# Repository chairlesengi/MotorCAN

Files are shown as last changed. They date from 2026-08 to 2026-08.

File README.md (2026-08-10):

# MotorCAN
CANBus based FOC motor driver board designed for drone gimbal motors for node-based control, designed in KiCad.

Features:
  - STM32G431 processor core for SimpleFOC software and CAN communication
  - 3.3V CAN communication for easy logic level support
  - Runs on 20-26V DC
  - Integrated magnetic absolute encoder (MT6816CT)
  - Handles up to ~3A of motor current

This driver is designed to be a fully integrated solution that mounts to the back of a gimbal motor with a diametrically magnetized magnet. For that reason, it includes an absoulute magnetic encoder and leverages the current sensing capabilities of the DRV8316C driver to maintain a continous measurement of the position of the rotor of the motor and its magnetic field. Then, the STM32 running SimpleFOC calculates the exact currents on each phase needed to create a magnetic torque on the motor that is 90 degrees from the magnetic field and therefore gives the greatest overall control of the motor. This chip also has a 3.3V CAN chip so it can link up to a simple 4 wire network of muliple of these boards for applications like camera gimbals.

Credits:
SimpleFOC: https://github.com/simplefoc
KiCad: https://www.kicad.org

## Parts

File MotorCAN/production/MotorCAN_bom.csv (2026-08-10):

Designator | Footprint | Quantity | Value | LCSC Part #
C1, C2 | 0402 | 2 | 10pF
C10, C11, C12, C3, C4, C5, C6, C7, C8, C9 | 1206 | 10 | 10uF
C13, C16, C20, C21, C22, C23, C27, C28 | 0402 | 8 | 100nF
C14, C24, C25 | 0603 | 3 | 1uF
C15 | 0603 | 1 | 47nF
C17, C18, C19 | 0603 | 3 | 1nF
C26 | 1206 | 1 | 22uF
C29 | CP_Elec_6.3x7.7 | 1 | 100uF
CN1, CN4, CN5, CN6 | CONN-SMD_3P-P1.00_MEGASTAR_ZX-SH1.0-3PWT | 4 | ZX-SH1.0-3PWT | C7430445
CN2, CN3 | CONN-SMD_4P-P1.25_XUNPU_WAFER-GH1.25-4PWB | 2 | WAFER-GH1.25-4PWB | C3029379
D1 | D_SOD-123 | 1 | 4.7V Zener
D2 | SOT-23-3_L2.9-W1.3-P1.90-LS2.4-BR | 1 | PESD2CANFD24V-K | C5278878
D3 | D_SMB | 1 | 26V
FB1 | 0603 | 1 | 600@100MHz
J2 | AMASS_XT30PW-M_1x02_P2.50mm_Horizontal | 1 | PWR IN
J3 | AMASS_XT30PW-F_1x02_P2.50mm_Horizontal | 1 | PWR OUT
L1 | IND-SMD_L4.0-W4.0 | 1 | 47uH | C18222004
M1 | SolderWirePad_1x01_SMD_2x4mm | 1 | A
M2 | SolderWirePad_1x01_SMD_2x4mm | 1 | B
M3 | SolderWirePad_1x01_SMD_2x4mm | 1 | C
Q1 | SOT-23 | 1 | 2N7002
R1 | 0603 | 1 | 120
R10, R11, R13, R14, R9 | 0603 | 5 | 10k
R12, R2, R7 | 0603 | 3 | 100k
R3 | 0603 | 1 | 22k
R4, R5, R6, R8 | 0603 | 4 | 100
U1 | LQFP-48_L7.0-W7.0-P0.50-LS9.0-BL | 1 | STM32G431CBT6 | C529355
U2 | VQFN-40_L7.0-W5.0-P0.50-BL-EP5.7 | 1 | DRV8316CRRGFR | C5447274
U3 | SOIC-8_L4.9-W3.9-P1.27-LS6.0-BL | 1 | SN65HVD230DR | C12084
U4 | SOP-8_L4.9-W3.9-P1.27-LS6.0-BL-1 | 1 | MT6816CT-AKD-R | C2987620
X1 | CRYSTAL-SMD_4P-L2.0-W1.6-BL-A | 1 | XL7EL89CKI-111YLC-24M | C2965580

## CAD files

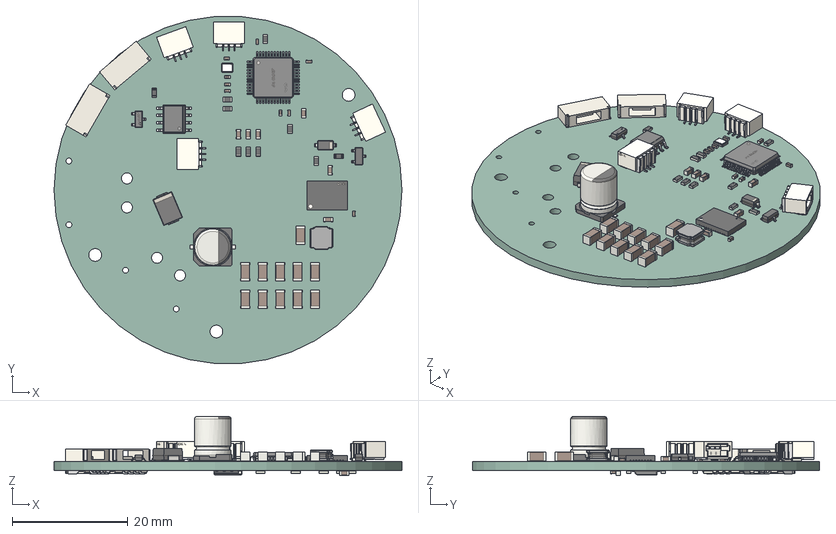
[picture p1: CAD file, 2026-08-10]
MotorCAN/.step
60.0 x 59.8 x 10.2 mm
C_0402_1005Metric x 10
SOT-23-3P_L2.9-W1.3-H1.0-LS2.4-P0.95
C_1206_3216Metric x 11
LQFP-48_L7.0-W7.0-H1.4-LS9.0-P0.50
CRYSTAL-SMD_4P-L2.0-W1.6-BL-A
C_0603_1608Metric x 7
R_0603_1608Metric x 15
CONN-SMD_3P-P1.00_MEGASTAR_ZX-SH1.0-3PWT x 4
SOIC-8_L4.9-W3.9-H1.7-LS6.0-P1.27
CP_Elec_6.3x7.7
IND-SMD_L4.0-W4.0-H1.9
VQFN-40_L7.0-W5.0-P0.50-BL-EP5.7
CONN-SMD_4P-P1.25_XUNPU_WAFER-GH1.25-4PWB x 2
D_SOD-123
SOT-23
D_SMB
SOP-8_L4.9-W3.9-P1.27-LS6.0-BL-1
MotorCAN_PCB

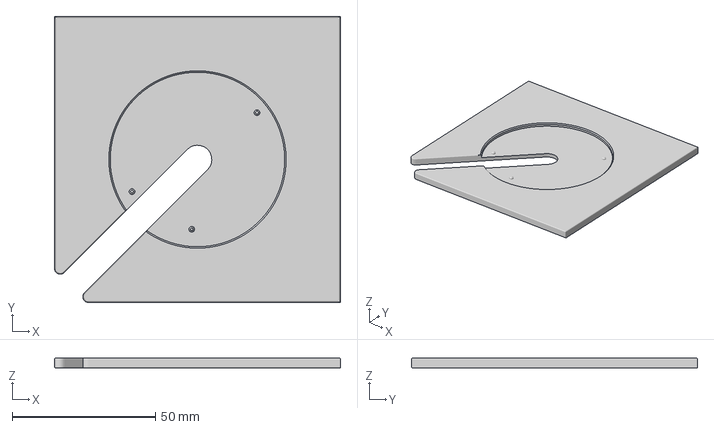
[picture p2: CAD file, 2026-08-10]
MotorCAN/HolderCAN.3mf
100.0 x 100.0 x 3.51 mm

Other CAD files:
MotorCAN/MotorCAN.step

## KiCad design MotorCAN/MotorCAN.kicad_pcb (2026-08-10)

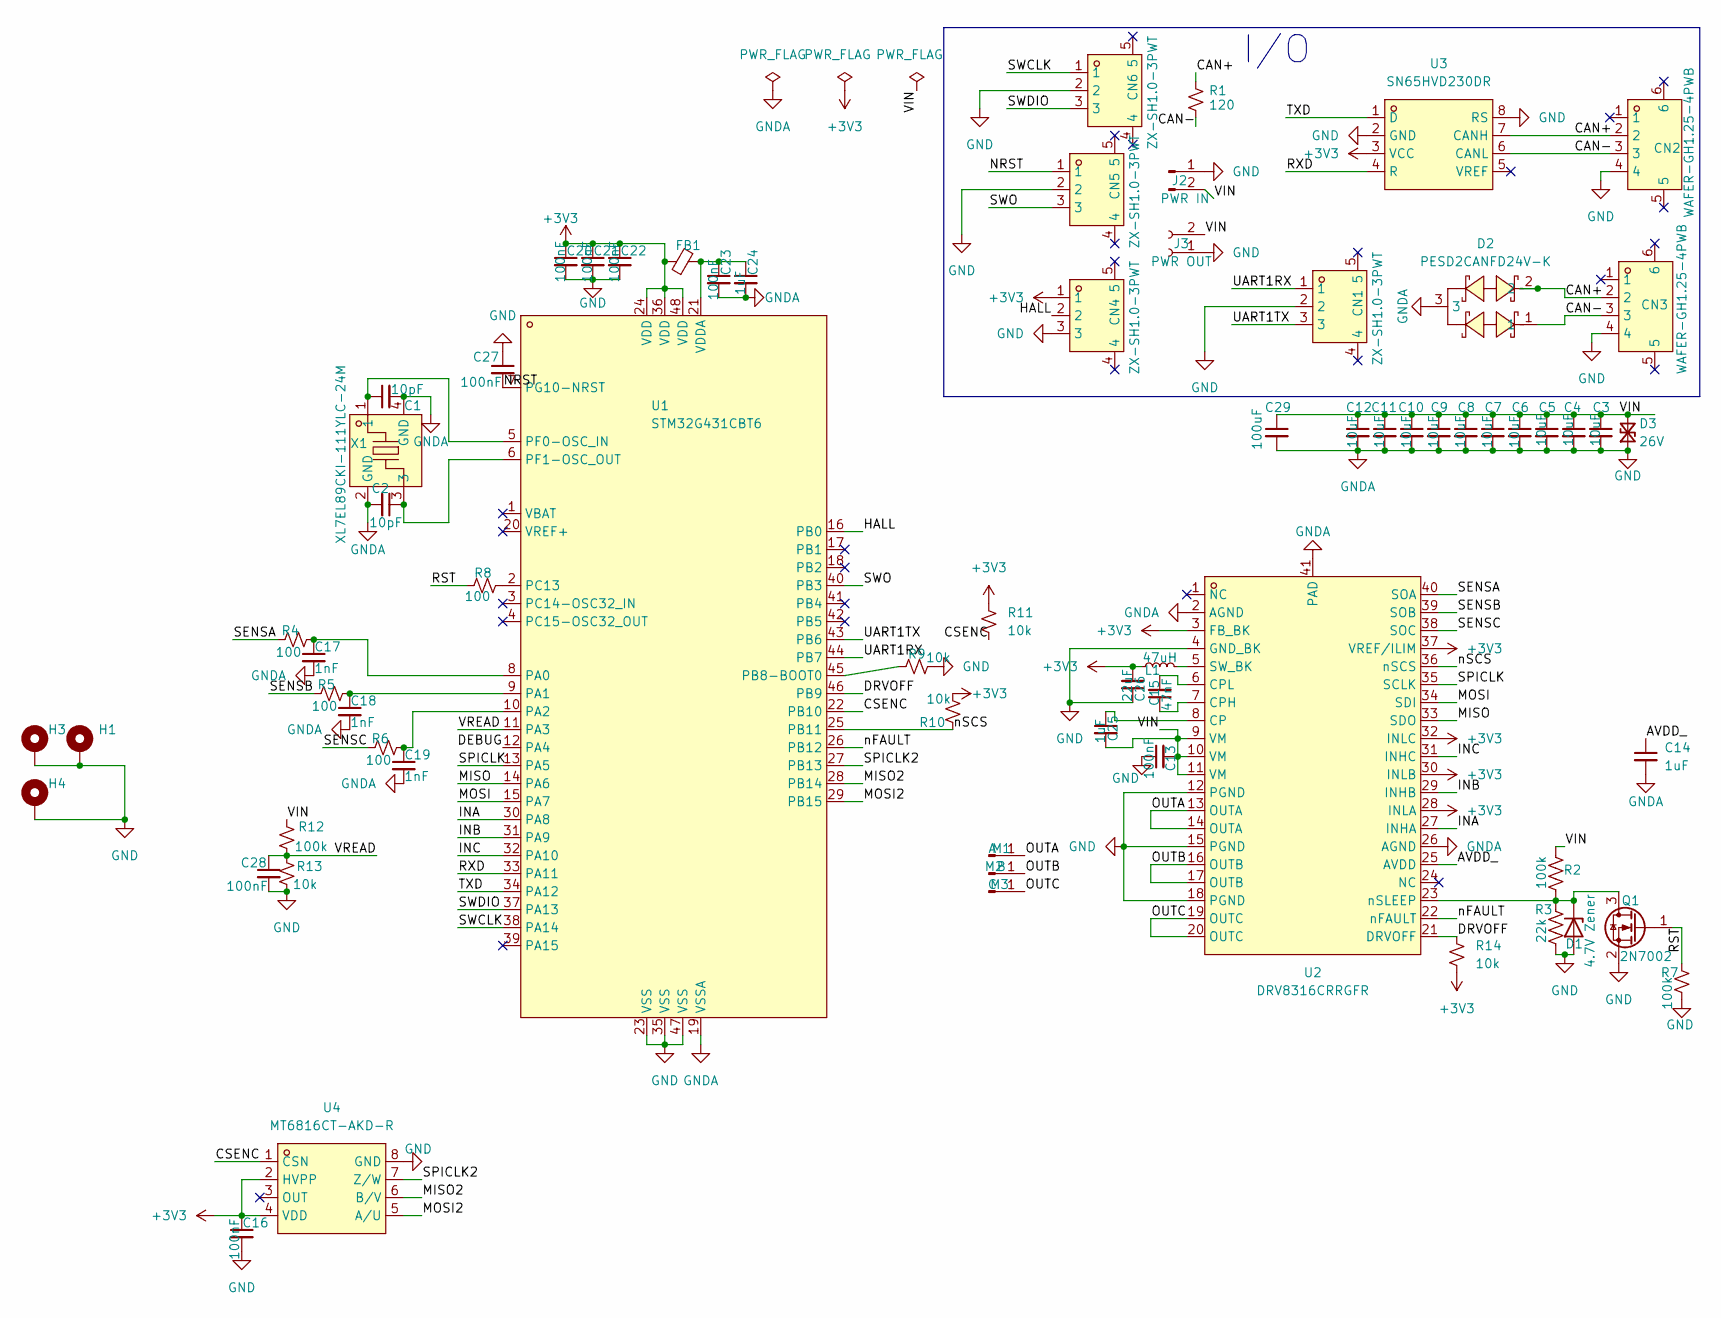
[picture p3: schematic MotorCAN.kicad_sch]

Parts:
C1, C2: 10pF; C_0402_1005Metric
C3, C4, C5, C6, C7, C8, C9, C10, C11, C12: 10uF; C_1206_3216Metric
C13, C16, C20, C21, C22, C23, C27, C28: 100nF; C_0402_1005Metric
C14, C24, C25: 1uF; C_0603_1608Metric
C15: 47nF; C_0603_1608Metric
C17, C18, C19: 1nF; C_0603_1608Metric
C26: 22uF; C_1206_3216Metric
C29: 100uF; CP_Elec_6.3x7.7
CN1, CN4, CN5, CN6: ZX-SH1.0-3PWT; CONN-SMD_3P-P1.00_MEGASTAR_ZX-SH1.0-3PWT; MPN ZX-SH1.0-3PWT; LCSC Part C7430445
CN2, CN3: WAFER-GH1.25-4PWB; CONN-SMD_4P-P1.25_XUNPU_WAFER-GH1.25-4PWB; MPN WAFER-GH1.25-4PWB; LCSC Part C3029379
D1: 4.7V Zener; D_SOD-123
D2: PESD2CANFD24V-K; SOT-23-3_L2.9-W1.3-P1.90-LS2.4-BR; MPN PESD2CANFD24V-K; LCSC Part C5278878
D3: 26V; D_SMB
FB1: 600@100MHz; R_0603_1608Metric
H1, H3, H4: MountingHole_Pad; MountingHole_2.2mm_M2_ISO14580_Pad_TopBottom
J2: PWR IN; AMASS_XT30PW-M_1x02_P2.50mm_Horizontal
J3: PWR OUT; AMASS_XT30PW-F_1x02_P2.50mm_Horizontal
L1: 47uH; IND-SMD_L4.0-W4.0
M1: A; SolderWirePad_1x01_SMD_2x4mm
M2: B; SolderWirePad_1x01_SMD_2x4mm
M3: C; SolderWirePad_1x01_SMD_2x4mm
Q1: 2N7002; SOT-23
R1: 120; R_0603_1608Metric
R2, R7, R12: 100k; R_0603_1608Metric
R3: 22k; R_0603_1608Metric
R4, R5, R6, R8: 100; R_0603_1608Metric
R9, R10, R11, R13, R14: 10k; R_0603_1608Metric
U1: STM32G431CBT6; LQFP-48_L7.0-W7.0-P0.50-LS9.0-BL; MPN STM32G431CBT6; LCSC Part C529355
U2: DRV8316CRRGFR; VQFN-40_L7.0-W5.0-P0.50-BL-EP5.7; MPN DRV8316CRRGFR; LCSC Part C5447274
U3: SN65HVD230DR; SOIC-8_L4.9-W3.9-P1.27-LS6.0-BL; MPN SN65HVD230DR; LCSC Part C12084
U4: MT6816CT-AKD-R; SOP-8_L4.9-W3.9-P1.27-LS6.0-BL-1; MPN MT6816CT-AKD-R; LCSC Part C2987620
X1: XL7EL89CKI-111YLC-24M; CRYSTAL-SMD_4P-L2.0-W1.6-BL-A; MPN XL7EL89CKI-111YLC-24M; LCSC Part C2965580

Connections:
+3V3: C16.1, C20.1, C21.1, C22.1, C26.2, CN4.1, FB1.1, L1.1, R10.1, R11.1, R14.2, U1.24 (VDD), U1.36 (VDD), U1.48 (VDD), U2.3 (FB_BK), U2.28 (INLA), U2.30 (INLB), U2.32 (INLC), U2.37 (VREF/ILIM), U3.3 (VCC), U4.2 (HVPP), U4.4 (VDD)
/AVDD_: C14.1, U2.25 (AVDD)
/CAN+: CN2.2, CN3.2, D2.2, R1.1, U3.7 (CANH)
/CAN-: CN2.3, CN3.3, D2.1, R1.2, U3.6 (CANL)
/CSENC: R11.2, U1.22 (PB10), U4.1 (CSN)
/DEBUG: U1.12 (PA4)
/DRVOFF: R14.1, U1.46 (PB9), U2.21 (DRVOFF)
/HALL: CN4.2, U1.16 (PB0)
/INA: U1.30 (PA8), U2.27 (INHA)
/INB: U1.31 (PA9), U2.29 (INHB)
/INC: U1.32 (PA10), U2.31 (INHC)
/MISO: U1.14 (PA6), U2.33 (SDO)
/MISO2: U1.28 (PB14), U4.6 (B/V)
/MOSI: U1.15 (PA7), U2.34 (SDI)
/MOSI2: U1.29 (PB15), U4.5 (A/U)
/NRST: C27.2, CN5.1, U1.7 (PG10-NRST)
/OUTA: M1.1 (Pin_1_1), U2.13 (OUTA), U2.14 (OUTA)
/OUTB: M2.1 (Pin_1_1), U2.16 (OUTB), U2.17 (OUTB)
/OUTC: M3.1 (Pin_1_1), U2.19 (OUTC), U2.20 (OUTC)
/RST: Q1.1 (G), R7.1, R8.1
/RXD: U1.33 (PA11), U3.4 (R)
/SENSA: R4.1, U2.40 (SOA)
/SENSB: R5.1, U2.39 (SOB)
/SENSC: R6.1, U2.38 (SOC)
/SPICLK: U1.13 (PA5), U2.35 (SCLK)
/SPICLK2: U1.27 (PB13), U4.7 (Z/W)
/SWCLK: CN6.1, U1.38 (PA14)
/SWDIO: CN6.3, U1.37 (PA13)
/SWO: CN5.3, U1.40 (PB3)
/TXD: U1.34 (PA12), U3.1 (D)
/UART1RX: CN1.1, U1.44 (PB7)
/UART1TX: CN1.3, U1.43 (PB6)
/VIN: C3.1, C4.1, C5.1, C6.1, C7.1, C8.1, C9.1, C10.1, C11.1, C12.1, C13.2, C25.2, C29.1, D3.2 (A2), J2.2, J3.2, R2.1, R12.1, U2.9 (VM), U2.10 (VM), U2.11 (VM)
/VREAD: C28.1, R12.2, R13.1, U1.11 (PA3)
/nFAULT: U1.26 (PB12), U2.22 (nFAULT)
/nSCS: R10.2, U1.25 (PB11), U2.36 (nSCS)
GND: C1.2, C2.2, C3.2, C4.2, C5.2, C6.2, C7.2, C8.2, C9.2, C10.2, C11.2, C12.2, C13.1, C14.2, C16.2, C17.2, C18.2, C19.2, C20.2, C21.2, C22.2, C23.2, C24.2, C26.1, C27.1, C28.2, C29.2, CN1.2, CN2.4, CN3.4, CN4.3, CN5.2, CN6.2, D1.2 (A), D2.3, D3.1 (A1), H1.1 (1_1), H3.1 (1_1), H4.1 (1_1), J2.1, J3.1, Q1.2 (S), R3.2, R7.2, R9.2, R13.2, U1.19 (VSSA), U1.23 (VSS), U1.35 (VSS), U1.47 (VSS), U2.2 (AGND), U2.4 (GND_BK), U2.12 (PGND), U2.15 (PGND), U2.18 (PGND), U2.26 (AGND), U2.41 (PAD), U3.2 (GND), U3.8 (RS), U4.8 (GND), X1.2 (GND), X1.4 (GND)
unnamed: D1.1 (K), Q1.3 (D), R2.2, R3.1, U2.23 (nSLEEP)
unnamed: C17.1, R4.2, U1.8 (PA0)
unnamed: C18.1, R5.2, U1.9 (PA1)
unnamed: C19.1, R6.2, U1.10 (PA2)
unnamed: R9.1, U1.45 (PB8-BOOT0)
unnamed: R8.2, U1.2 (PC13)
unnamed: C1.1, U1.5 (PF0-OSC_IN), X1.1
unnamed: C2.1, U1.6 (PF1-OSC_OUT), X1.3
unnamed: C23.1, C24.1, FB1.2, U1.21 (VDDA)
unnamed: C25.1, U2.8 (CP)
unnamed: C15.1, U2.7 (CPH)
unnamed: C15.2, U2.6 (CPL)
unnamed: L1.2, U2.5 (SW_BK)

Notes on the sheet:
I/O

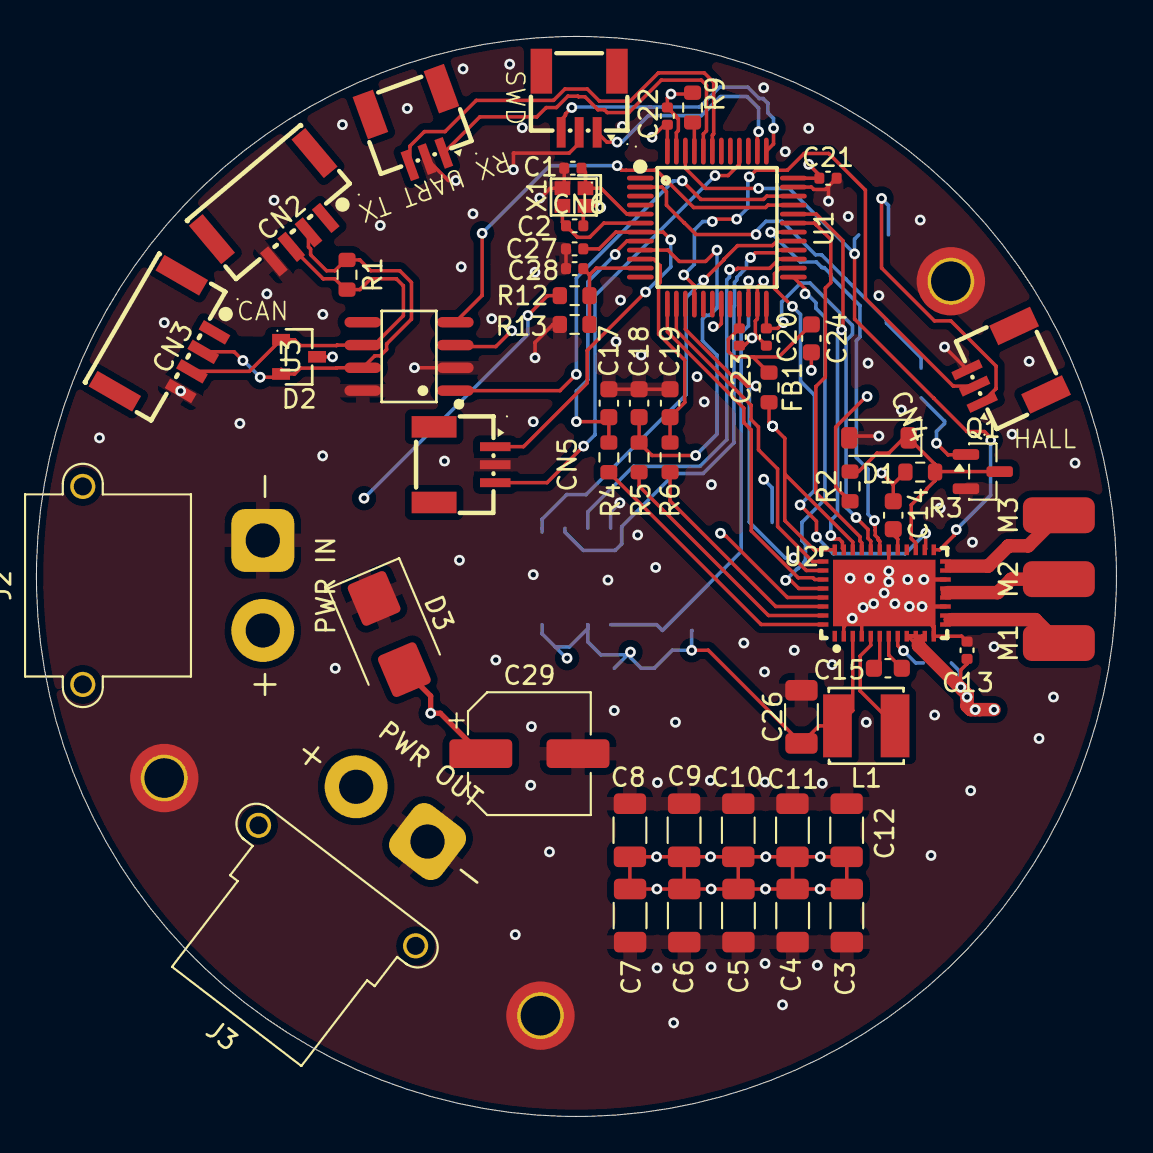
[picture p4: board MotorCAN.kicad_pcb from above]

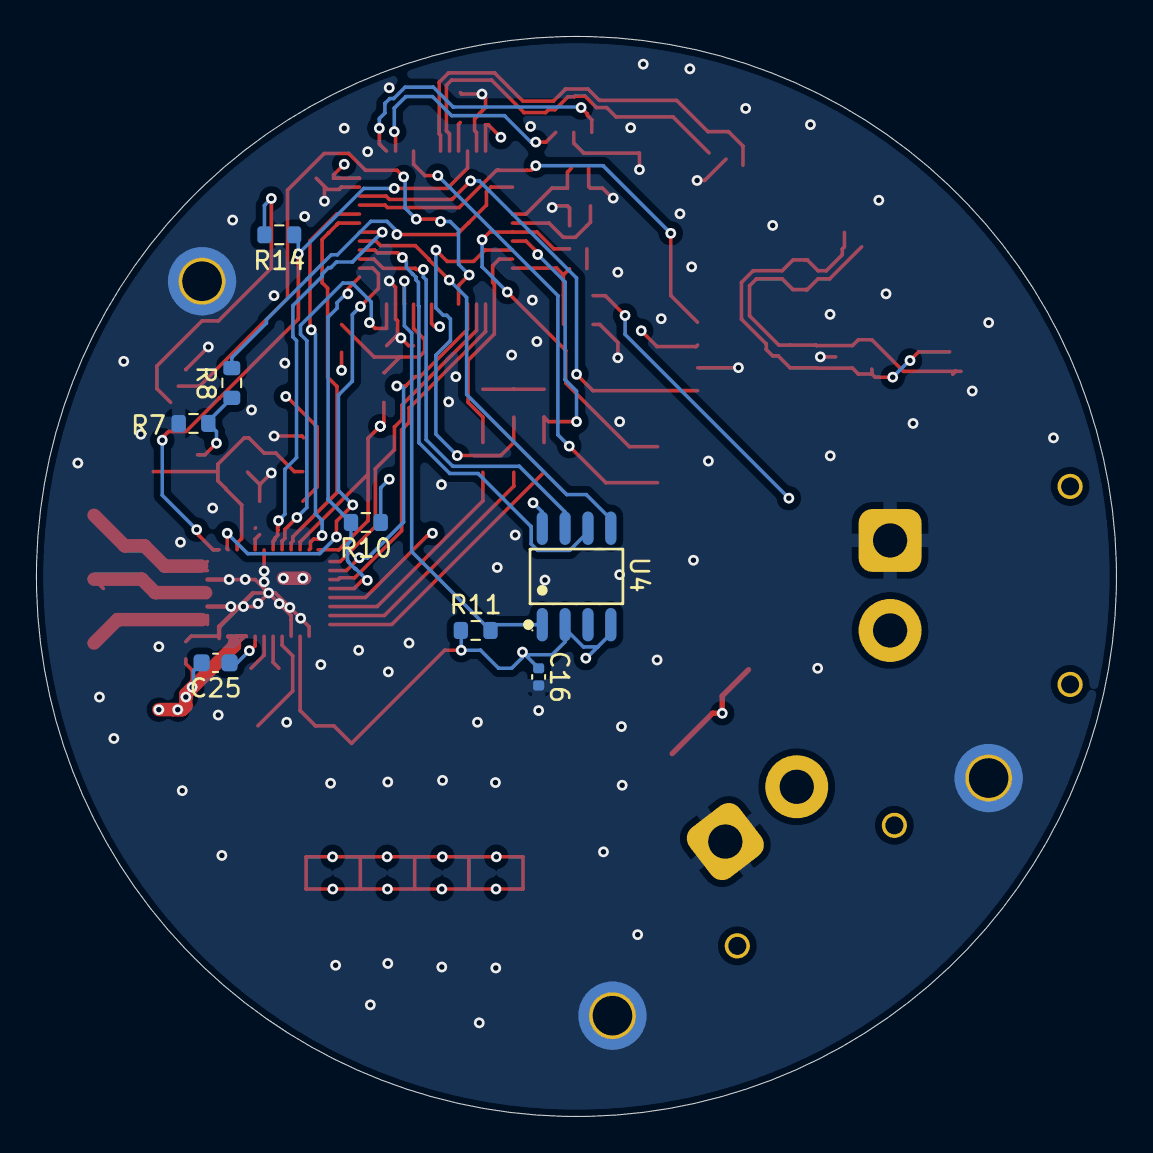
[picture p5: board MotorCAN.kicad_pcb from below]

Board: 4 copper layers, 60.0 x 60.0 mm, 68 parts (8 on the bottom side), 49 nets.

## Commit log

2026-06-06 Added .pcb, .sch from previous work
    Had worked on project before putting on github so moving files in done now
2026-06-06 ok actually now I fixed the repo
    Yayy
    [MotorCAN.kicad_pcb, MotorCAN.kicad_sch, freerouting.dsn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]
2026-08-10 Added finalized design, with some issues fixed
    [.step, HolderCAN.3mf, MotorCAN.kicad_pcb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]
